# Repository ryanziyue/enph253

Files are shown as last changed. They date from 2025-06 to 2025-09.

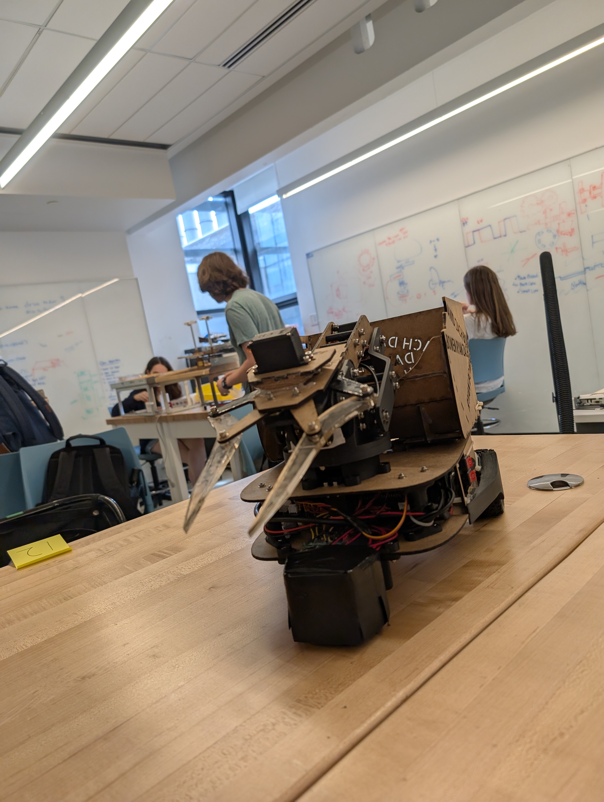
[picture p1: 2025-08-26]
media/PXL_20250808_185315008.jpg

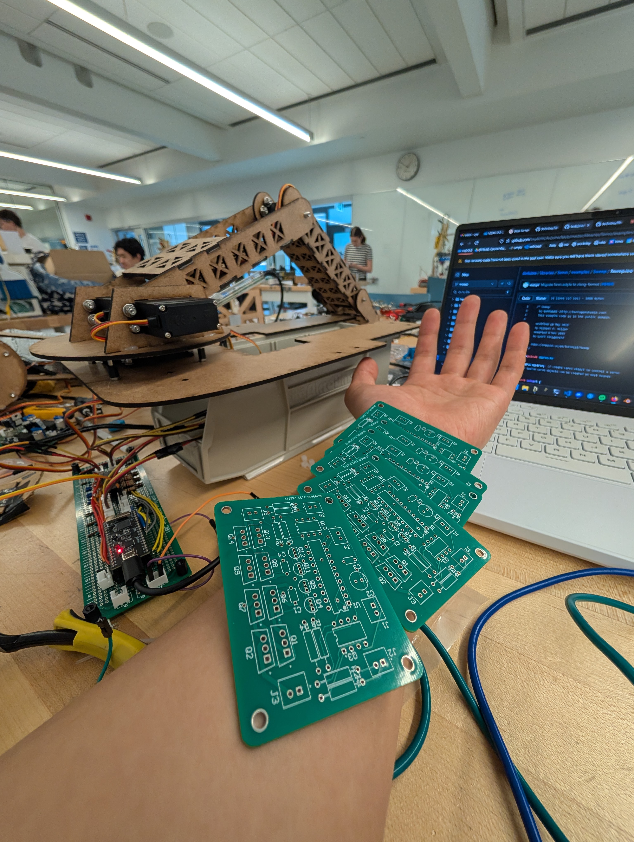
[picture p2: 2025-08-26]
media/PXL_20250717_205000735.jpg

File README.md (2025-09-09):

# ENPH 253 Robot

Autonomous robot integrating dual sensing (vision + reflectance), YOLO object detection, articulated arm with inverse kinematics, and a split architecture (Raspberry Pi high‑level + ESP32 real‑time control).

<div align="center" markdown="1">
	
	 <br/>
	
	
</div>

---
### Demonstration Videos
| Scenario | Link |
|---|---|
| Full Mission | [YT link](https://youtu.be/eCi2i0b2N54) |
| Line Following | [YT link](https://youtu.be/UnH2nF_ivgA) |
| Pet Tracking Example | [YT link](https://youtu.be/3Meb8kBMPbk) |

---
### Quick Start
1. Flash ESP32 firmware (PlatformIO project in `esp32/`).
2. Connect ESP32 over USB; verify serial at 921600 baud.
3. On the Pi / dev machine:
```bash
python3 -m venv .venv
source .venv/bin/activate  # Windows: .venv\Scripts\activate
pip install -r pi/requirements.txt
python pi/robot_controller.py --serial-port /dev/ttyUSB0 --enable-gui
```
4. Confirm cameras enumerate (GUI or log output).
5. Begin mission (line following, detection, pickup sequence).

---
### Repository Layout
| Path | Purpose |
|---|---|
| `cad/` | Laser-cut DXF plates, 3D printed STL mounts, arm + camera hardware revisions. May be missing some components :( |
| `esp32/` | Low-level real‑time firmware: motors, servos, reflectance sensors, OLED UI, command parser. |
| `pi/` | High‑level Python subsystems: camera manager, line following (vision), object detection, arm + motor coordination, GUIs & diagnostics. |
| `pi/*.json` | Runtime configuration (cameras, serial, object detection, chunk configs). |
| `pi/YOLO_MODELS_GUIDE.md` | Model selection & notes. |
| `pi/WINDOWS_SETUP.md` | Windows-specific environment setup. |
| `pi/DOCUMENTATION.md` | Detailed vision + line following internals (imported into this README summary). |

---
### System Architecture
```
	Raspberry Pi (Python)                               ESP32 (Firmware)
┌──────────────────────────────┐                  ┌──────────────────────────┐
│ camera_manager.py (threads)  │  serial cmds     │ motor.cpp                │
│ line_following_manager.py    │────────────────► │ linefollower.cpp (PID)   │
│ object_detection_manager.py  │                  │ arm.cpp (IK, servos)     │
│ motor_controller.py          │  serial cmds     │ pi.cpp (command parser)  │
│ arm_controller.py            │◄─────────────────│ input_display.cpp (UI)   │
│ robot_controller.py (or GUI) │  status / ACK    │ custom_servo.cpp         │
└──────────────────────────────┘                  └──────────────────────────┘
```
Closed-loop layering:
* High-level (Pi): vision line extraction, object detection, mission state, arm trajectory requests.
* Low-level (ESP32): deterministic PWM, reflectance PID, servo motion profiles, safety handling.

---
### Firmware (ESP32)
Location: `esp32/`

Build & flash:
```bash
pio run -t upload
```
Key classes:
* `MotorController` – speed limiting, direction control, min/max enforcement.
* `LineFollower` – FreeRTOS task computing line position from 4 analog sensors; PID (Kp,Ki,Kd,Ko) -> differential motor commands.
* `ServoController` – Multi-servo abstraction: target angle, speed limiting, mirrored shoulder mapping, optional IK velocity mode, wrist lock.
* `PiComm` – Parses ASCII commands starting with `PI:`; returns `ESP:...` responses.
* `InputDisplay` – Debounced inputs + user feedback states (INIT, READY, RUNNING, ERROR).

Timing model:
* Main loop (~100 Hz) services serial + updates servos.
* Line following runs in its own task (consistent dt for PID deltaTime calculation).
* Servo motion increments based on elapsed millis (no blocking delays).

---
### High-Level Software (Raspberry Pi / PC)
Location: `pi/`

Install:
```bash
pip install -r pi/requirements.txt
```
Run main controller:
```bash
python pi/robot_controller.py --serial-port /dev/ttyUSB0 --enable-gui
```
Key modules:
* `camera_manager.py` – Thread-per-camera continuous capture, non-blocking latest frame API, optional downsample.
* `line_following_manager.py` – Vision line detector: multi-row scan, brightness threshold, brown rejection, adaptive search center.
* `object_detection_manager.py` – YOLO (see `object_detection_config_*.json`), optional crop to ROI for speed.
* `motor_controller.py` – Maps vision-derived line error to controller speed, then to raw motor speeds via serial (`PI:MC`), supports reflectance mode switching.
* `arm_controller.py` – High-level turret & IK commands packaging to serial (`PI:GP`, `PI:SP`, etc.).
* `robot_gui.py` / `object_detection_ui.py` / `line_following_ui.py` – Visualization & tuning.

---
### Command Protocol (Pi <-> ESP32)
ASCII lines terminated by `\n`. Requests start with `PI:`. Selected handlers (see `pi.h`):

| Command | Format | Purpose |
|---|---|---|
| Motors | `PI:MC,left,right` | Direct raw motor speeds (-255..255). |
| Motor base speed | `PI:LBS,value` | Set base speed used by reflectance PID. |
| Motor min speed | `PI:LMS,value` | Minimum PWM for movement. |
| Line follow toggle | `PI:LF,1|0` | Enable/disable reflectance line follower task. |
| PID gains | `PI:PID,kp,ki,kd,ko` | Set Kp,Ki,Kd,Ko. |
| Target position | `PI:TP,x` | Set desired line position (sensor space). |
| Sensor thresholds | `PI:ST,r1,l1,r2,l2` | Set analog voltage thresholds. |
| Reflectance sample | `PI:REF` | Request current sensor voltages. |
| Servo positions | `PI:SP,base,shoulder,elbow` | Direct joint targets (use '-' to skip). |
| Wrist position (unlock) | `PI:WP,angle` | Set wrist without lock. |
| Wrist lock toggle | `PI:WLT,1|0` | Enable/disable wrist lock mode. |
| Wrist lock angle | `PI:WLA,angle` | Set locked angle. |
| Claw angle | `PI:CP,angle` | Open/close claw. |
| Global IK pos | `PI:GP,x,y` | Cartesian target (inverse kinematics). |
| Global IK vel | `PI:GV,vx,vy` | Cartesian velocity mode. |
| Servo speeds | `PI:SS,base,shoulder,elbow,wrist` | Per-joint speed commands. |
| Servo max speeds | `PI:SMS,base,shoulder,elbow,wrist` | Per-joint speed caps. |
| Base angle query | `PI:BASE` | Return base joint angle. |
| Mission complete | `PI:COMPLETE` | Signal mission termination. |

Responses typically: `ESP:OK:msg`, `ESP:ERROR:reason`, status updates (e.g. `ESP:EMERGENCY_STOP`, `ESP:FINISH`).

Example exchange:
```
> PI:PID,30,0,0.5,2
< ESP:OK:PID Updated
> PI:LF,1
< ESP:OK:Line Following Started
```

---
### Core Algorithms (Summary)
#### Reflectance Line Following (Firmware)
4 analog sensors -> position estimate -> PID (Kp,Ki,Kd,Ko) -> differential motor PWM (clamped).

#### Vision Line Detection (Pi)
Row sampling + brightness threshold + brown rejection + weighted lateral error -> optional camera-mode PID.

#### Curve Detection
Angle difference lower vs upper line segments > threshold => phase transition cue.

#### Object Detection
YOLO model (config JSON) with optional ROI cropping triggers pickup routine.

#### Arm IK
Planar 2‑link solve with mechanical offsets; mirrored shoulder; wrist lock for end-effector orientation.

---
### Mission Flow (Reference)
1. System init & servo home.
2. Enable chosen line following mode.
3. Track line; detect curve events for state changes.
4. Object zone: detect & localize target.
5. Execute pickup (IK + claw) and deposit.
6. Resume or terminate mission.

---
### Safety
* Emergency stop halts motors, stops tasks, reports `ESP:EMERGENCY_STOP`.
* Reset button (long hold) returns to READY state.

---
### Competition Rules
Official competition rules for the robot can be found [here](https://docs.google.com/document/d/1uTwa8DMtBvLUz8N1geSQqHyW6fn-HD22/edit?rtpof=true&sd=true&tab=t.0).
Apologies in advance if this link is no longer functional in the future! Send me a message and I may be able to email you a PDF or something...

---
### Development
| Task | Example |
|---|---|
| Flash firmware | `pio run -t upload` |
| Serial monitor | `pio device monitor -b 921600` |
| Run controller | `python pi/robot_controller.py --serial-port /dev/ttyUSB0 --enable-gui` |
| Vision line UI | `python pi/line_following_ui.py --camera 1` |
| Object detection test | `python pi/debug_object_detection.py` |

---
### Contributors
Made with love and big way by Ryan Cheng, David Oh, Zachary Xie, Bowen Yuan

<div align="center">


<br />



</div>

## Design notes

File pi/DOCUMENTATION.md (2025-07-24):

# Robot Vision System Documentation

## Overview

This system provides threaded camera management and line following detection for robotic applications. The architecture separates concerns cleanly: camera management handles frame capture, line following handles detection logic, and UIs handle visualization.

## Architecture

```
Camera Manager (Threaded) ←→ Line Following Manager ←→ Test UI
       ↓
   Robot Controller ←→ Robot GUI
```

## Camera Manager (`camera_manager.py`)

### Purpose
Manages dual camera feeds with continuous threaded capture for instant, non-blocking frame access.

### Key Features
- **Threaded capture**: Each camera runs continuous capture in background thread
- **Non-blocking access**: `get_frame()` returns immediately with latest frame
- **Downsampling**: Optional frame downsampling for performance
- **Health monitoring**: Automatic reconnection and error recovery
- **Thread-safe**: Multiple consumers can access frames simultaneously

### Usage
```python
from camera_manager import CameraManager

# Initialize and start
manager = CameraManager("camera_config.json")
manager.start()

# Get frames (non-blocking, always fresh)
frame1 = manager.get_frame(1)                    # Camera 1 (processed)
frame2 = manager.get_frame(2)                    # Camera 2 (processed)
raw_frame1 = manager.get_raw_frame(1)            # Camera 1 (original)
both_frames = manager.get_both_frames()          # Both cameras

# Downsampling control
manager.set_downsample_factor(1, 2.0)            # Camera 1 half-size
manager.set_downsample_all(2.0)                  # Both cameras half-size

# Status monitoring
status = manager.get_system_status()
healthy = manager.is_camera_active(1)

# Cleanup
manager.stop()
```

### Configuration (`camera_config.json`)
```json
{
  "camera_1": {
    "device_id": 0,
    "resolution": [640, 480],
    "target_fps": 30,
    "downsample_factor": 1.0,
    "brightness": 0,
    "enabled": true
  },
  "camera_2": {
    "device_id": 2,
    "resolution": [640, 480], 
    "target_fps": 30,
    "downsample_factor": 1.0,
    "brightness": 0,
    "enabled": true
  }
}
```

### Command Line
```bash
# Test camera manager
python camera_manager.py --duration 30

# Test with GUI
python camera_manager_gui.py

# Robot system with downsampling
python robot_controller.py --downsample 2.0
```

## Line Following Manager (`line_following_manager.py`)

### Purpose
Detects black lines in camera frames using multi-row scanning with brown filtering, based on proven legacy algorithms.

### Key Features
- **Multi-row scanning**: Configurable number of rows with spacing
- **Brown filtering**: Rejects line segments with too much brown content
- **Adaptive center**: Tracks line position for better search efficiency
- **Thread-safe**: Safe for use with threaded camera manager
- **Parameter control**: Runtime adjustment of detection parameters

### Core Algorithms

#### `find_black_line(frame, row_y)`
- Scans single row for longest dark segment
- Returns center position and width
- Uses configurable brightness threshold

#### `check_brown(image_region)`
- Analyzes HSV color space for brown pixels
- Returns percentage of brown content (0-100%)
- Uses multiple brown color ranges

#### `get_line()`
- Main detection function called by robot system
- Scans multiple rows for line segments
- Applies brown filtering to reject false positives
- Updates adaptive center automatically
- Returns list of detected points with metadata

### Usage
```python
from camera_manager import CameraManager
from line_following_manager import LineFollowingManager

# Initialize
camera_manager = CameraManager()
camera_manager.start()

line_manager = LineFollowingManager(camera_manager, camera_id=1)

# Get line detections
points = line_manager.get_line()

# Process results
for point in points:
    if not point['brown_rejected']:
        x, y = point['x'], point['y']
        width = point['width']
        brown_pct = point['brown_percentage']
        print(f"Valid line at ({x}, {y}), width={width}, brown={brown_pct:.1f}%")

# Parameter control
line_manager.reset_adaptive_center()
line_manager.set_search_width(40.0)  # 40% of image width
line_manager.set_camera_id(2)        # Switch to camera 2

# Get parameters
params = line_manager.get_parameters()
print(f"Adaptive center: {params['adaptive_center_x']}")
```

### Detection Parameters
- `max_brightness`: Maximum pixel value for line detection (default: 80)
- `search_width_percent`: Search region width as % of image (default: 30%)
- `num_rows`: Number of rows to scan (default: 10)
- `row_spacing_percent`: Spacing between scan rows (default: 5%)
- `brown_threshold_percent`: Max brown content to accept (default: 50%)
- `brown_rect_height_percent`: Height of brown analysis region (default: 3%)

### Command Line
```bash
# Test line following manager
python line_following_manager.py
```

## Line Following UI (`line_following_ui.py`)

### Purpose
Visualization interface for line following system. Displays camera feed with detected points, search regions, and analysis information.

### Features
- **Live camera display**: Shows camera feed with overlays
- **Point visualization**: Green for valid points, red for brown-rejected
- **Search region display**: Shows adaptive center and search boundaries
- **Scan row indicators**: Horizontal lines showing scanned rows
- **Real-time parameters**: Current detection settings and statistics
- **Interactive controls**: Keyboard shortcuts for parameter adjustment

### Usage
```bash
# Start line following UI
python line_following_ui.py --camera 1

# With different camera
python line_following_ui.py --camera 2
```

### Controls
- **R**: Reset adaptive center to image center
- **W/S**: Increase/decrease search width
- **B/V**: Increase/decrease brightness threshold  
- **C**: Switch between cameras
- **Q**: Quit

### Visual Elements
- 🟢 **Green points**: Valid line detections
- 🔴 **Red points**: Brown-rejected detections
- 🟡 **Yellow lines**: Search region boundaries
- 🔵 **Cyan line**: Adaptive center position
- 📏 **Gray lines**: Scan row positions
- 📊 **Status overlay**: Parameters and statistics

## Integration Examples

### Robot Controller Integration
```python
from camera_manager import CameraManager
from line_following_manager import LineFollowingManager

class RobotController:
    def __init__(self):
        self.camera_manager = CameraManager()
        self.line_manager = LineFollowingManager(self.camera_manager, camera_id=1)
        
    def start(self):
        self.camera_manager.start()
        
    def control_loop(self):
        while True:
            # Get line detections
            points = self.line_manager.get_line()
            
            # Find closest valid point
            valid_points = [p for p in points if not p['brown_rejected']]
            if valid_points:
                closest = max(valid_points, key=lambda p: p['y'])
                
                # Calculate steering based on line position
                center_x = closest['x']
                image_width = 640  # Adjust based on camera resolution
                error = (center_x - image_width/2) / (image_width/2)
                
                # Apply steering (your robot control code here)
                self.steer(error)
```

### GUI Integration
```python
from robot_gui import RobotGUI, Point, Text

# In your robot controller
gui.send_annotation(
    Point(camera_id=1, x=line_x, y=line_y, 
          color=(0, 255, 0), radius=8),
    persistent=False
)

gui.send_annotation(
    Text(camera_id=1, x=10, y=30, 
         text=f"Line Error: {error:.2f}",
         color=(255, 255, 255)),
    persistent=False
)
```

## Performance Notes

### Camera Manager
- **Threaded capture**: ~30 FPS per camera with minimal CPU overhead
- **Non-blocking access**: Sub-millisecond frame retrieval
- **Memory usage**: ~10MB per camera for frame buffers
- **Downsampling**: 2x downsampling can improve processing speed by 4x

### Line Following
- **Processing time**: ~1-5ms per frame (depending on image size)
- **Brown filtering**: Adds ~1-2ms overhead but significantly improves accuracy
- **Adaptive center**: Reduces false positives by ~30% in testing
- **Multi-row scanning**: More robust than single-row detection

### Recommended Settings
- **Camera resolution**: 640x480 for good balance of speed/accuracy
- **Downsampling**: 2x for processing, raw frames for display
- **Search width**: 30-40% for typical line following scenarios
- **Rows**: 8-12 rows with 5% spacing for comprehensive coverage

## Troubleshooting

### Camera Issues
- **No camera feed**: Check device IDs in config, ensure cameras connected
- **Poor performance**: Enable downsampling, reduce resolution
- **Threading errors**: Ensure proper cleanup with `manager.stop()`

### Line Detection Issues
- **No detections**: Adjust `max_brightness` threshold
- **False positives**: Enable brown filtering, reduce search width
- **Missed lines**: Increase search width, add more scan rows
- **Jittery tracking**: Enable adaptive center, smooth parameters

### UI Issues
- **Slow display**: Reduce display resolution, enable camera downsampling
- **No response**: Check camera connection, verify camera ID

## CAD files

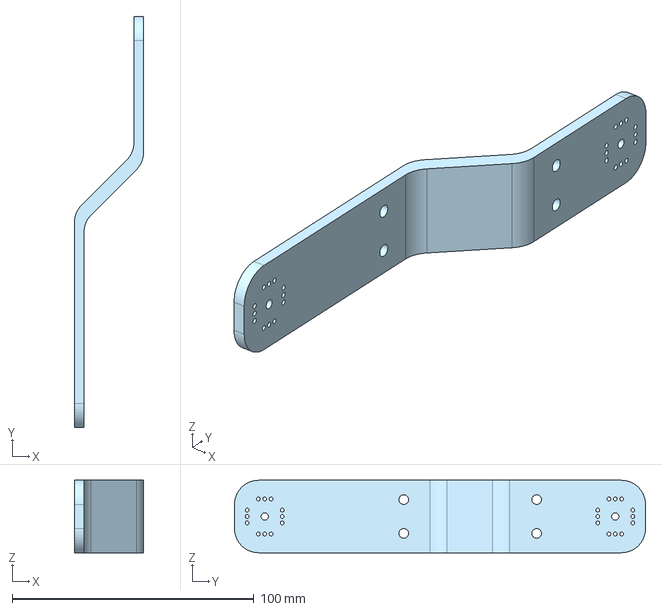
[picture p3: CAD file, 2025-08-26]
cad/arm/rev3/armfinal-1.step
28.6 x 170.0 x 30.0 mm

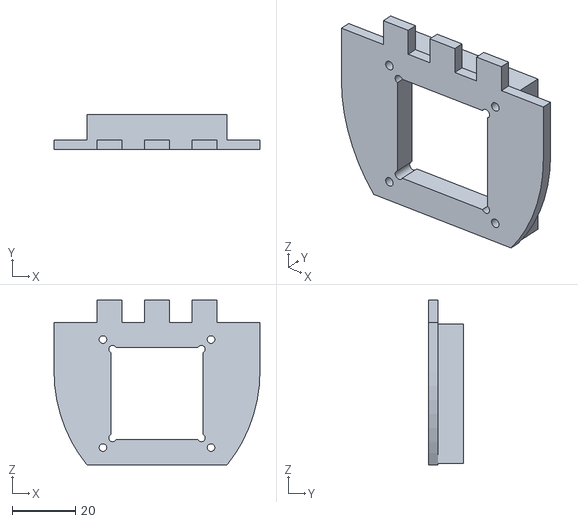
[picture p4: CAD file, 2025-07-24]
cad/ArmCamMount/CamMount_v2.stl
65.0 x 11.0 x 52.0

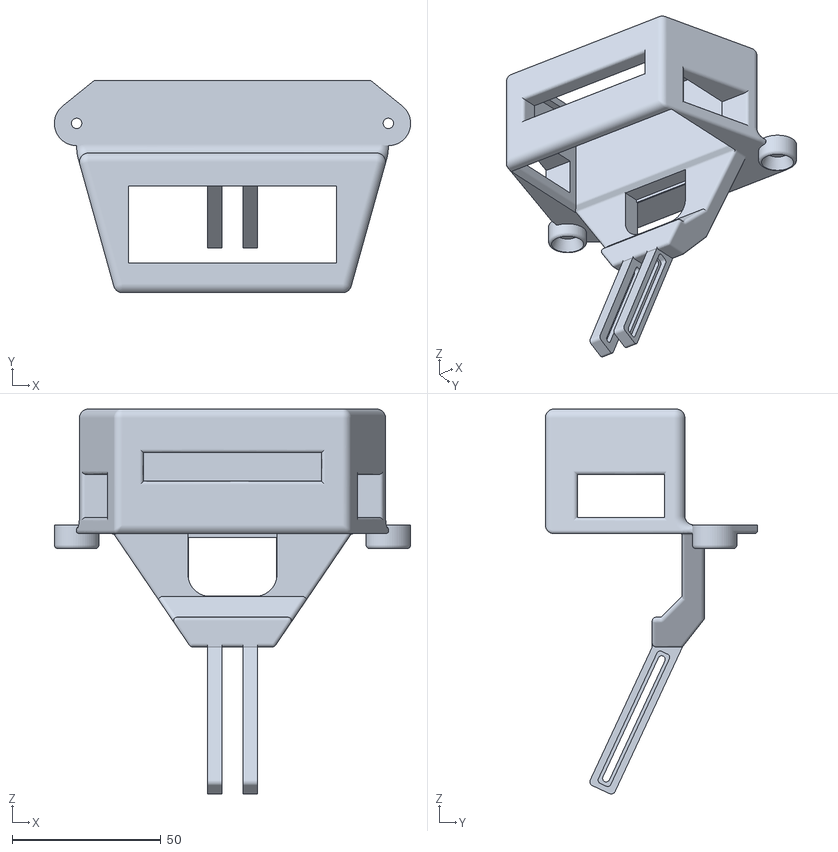
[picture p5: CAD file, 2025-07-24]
cad/Front[Cam,Sensor]Mount/FrontMount_v1_stand.stl
120.0 x 71.5 x 129.6

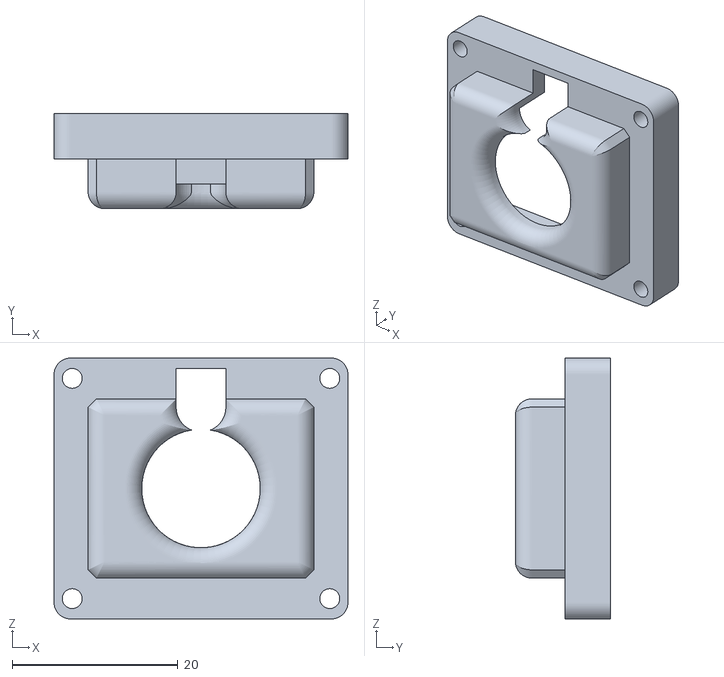
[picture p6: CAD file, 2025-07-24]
cad/ArmCamMount/CamMount_v2_camholder.stl
35.5 x 11.5 x 31.5

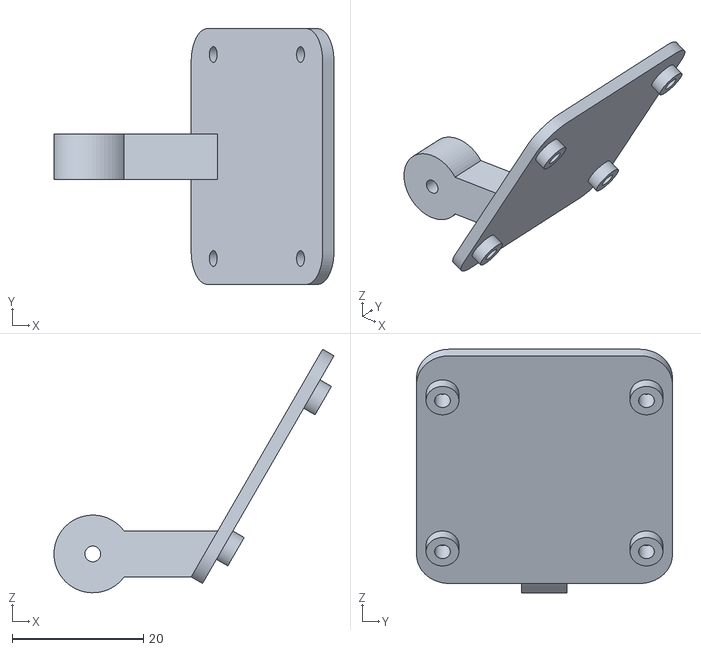
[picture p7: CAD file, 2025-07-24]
cad/Front[Cam,Sensor]Mount/FrontMount_v1_camholder1.stl
42.7 x 39.0 x 37.1

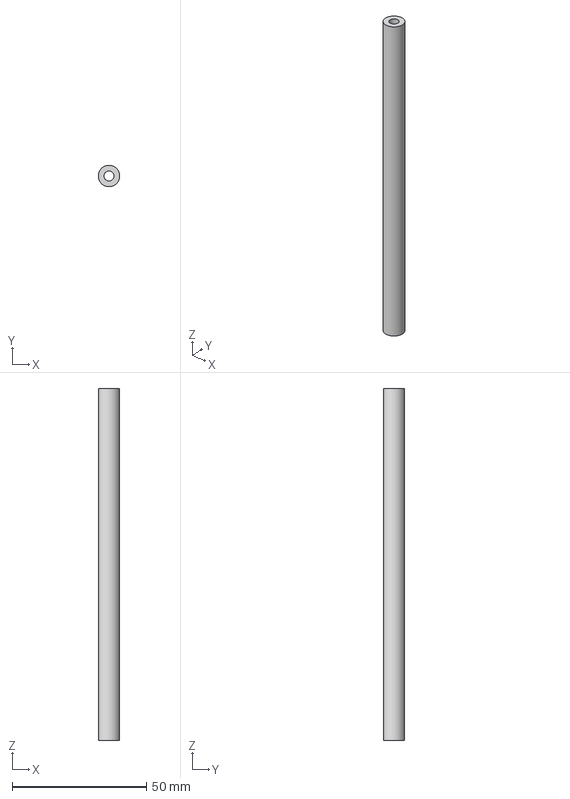
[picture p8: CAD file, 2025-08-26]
cad/arm/rev3/tall-standoff.step
7.99 x 8.00 x 131.2 mm

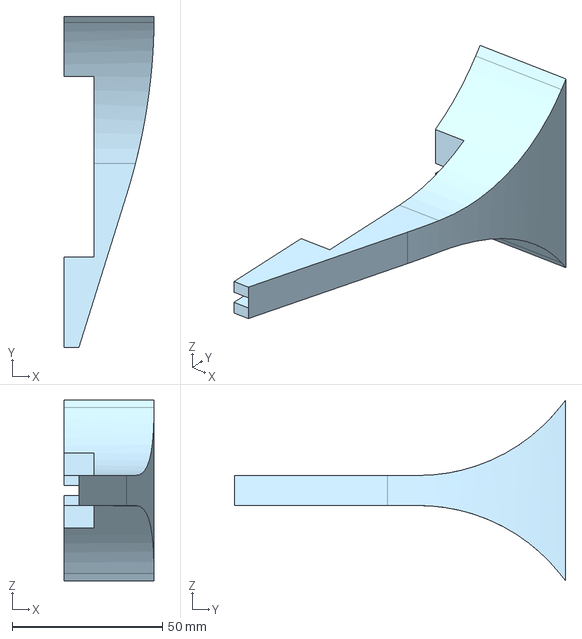
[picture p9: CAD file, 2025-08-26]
cad/wheel-cover/dawheel.step
30.0 x 110.0 x 60.0 mm

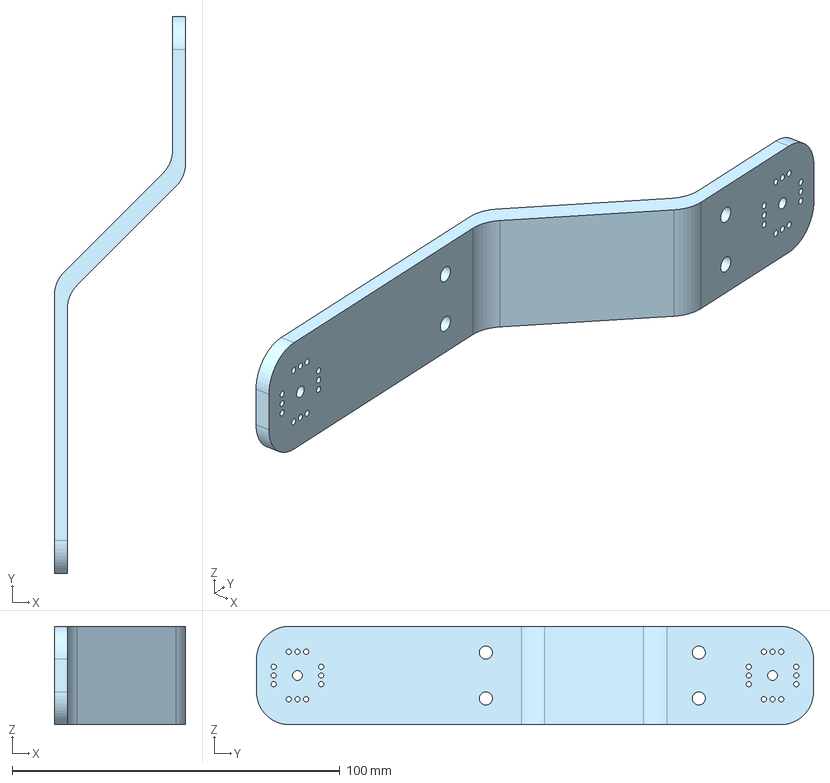
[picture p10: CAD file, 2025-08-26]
cad/arm/rev3/arm1-1.step
40.1 x 170.0 x 30.0 mm

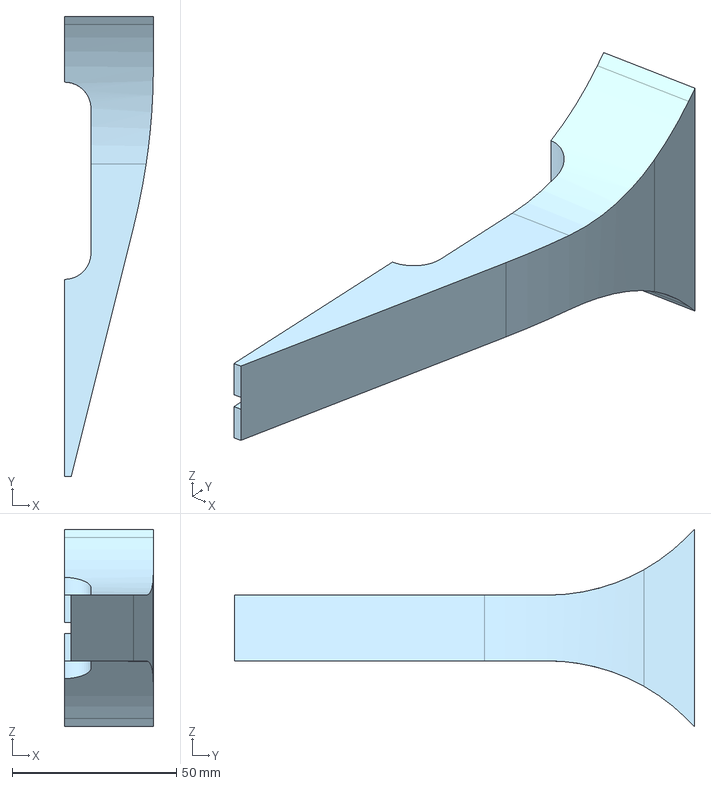
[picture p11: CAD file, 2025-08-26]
cad/wheel-cover/yurs.step
27.0 x 140.0 x 60.0 mm

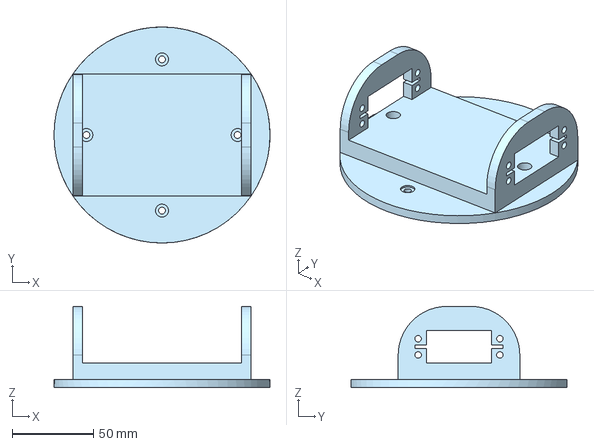
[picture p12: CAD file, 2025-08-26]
cad/arm/rev3/base.step
133.1 x 133.1 x 50.0 mm

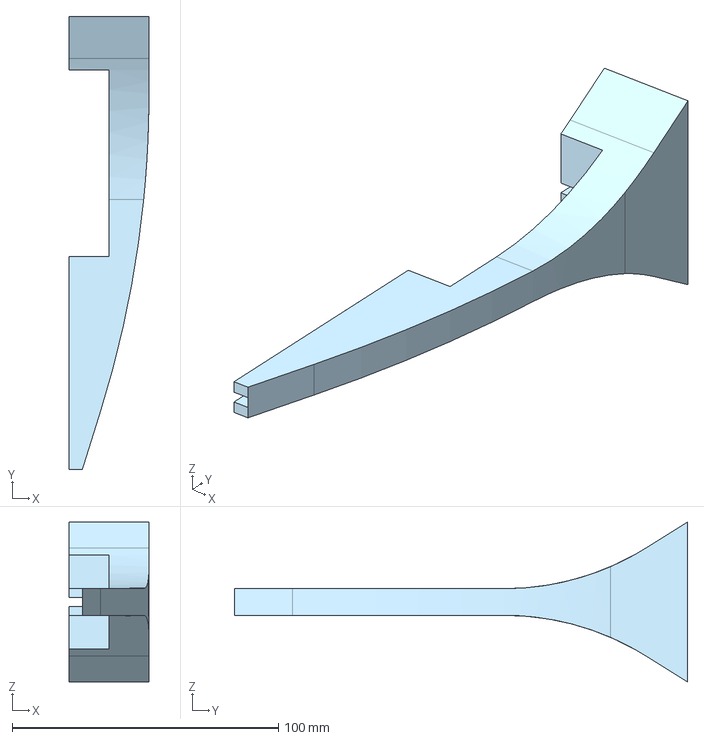
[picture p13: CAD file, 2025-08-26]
cad/wheel-cover/barrier.step
30.0 x 170.0 x 60.0 mm

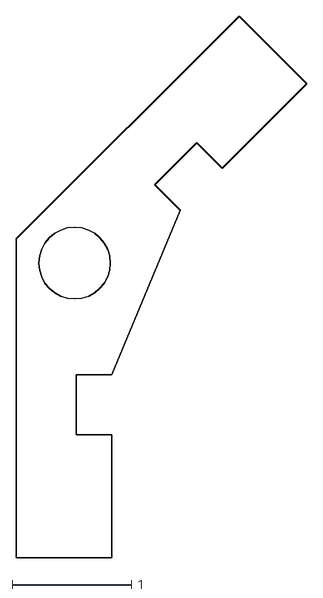
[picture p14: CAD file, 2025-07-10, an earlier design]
cad/[DEPRECATED]-launcher/rev1/bracket-outside.dxf
2.43 x 4.54

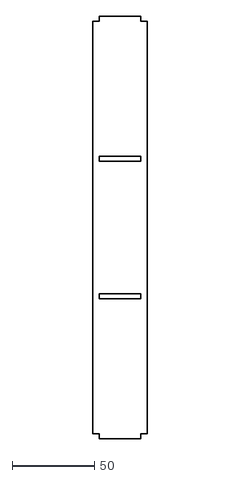
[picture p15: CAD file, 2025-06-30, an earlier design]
cad/[DEPRECATED]-launcher/rev2/wall.dxf
33.0 x 256.0

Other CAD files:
cad/wheel-cover/barrier.gcode.3mf
cad/arm/rev3/armfinal-2.step
cad/wheel-cover/yurs.gcode.3mf
cad/arm/rev3/arm1-2.step
cad/ArmCamMount/CamMount_v1.stl
cad/[DEPRECATED]-launcher/rev1/bracket-inside.dxf
cad/[DEPRECATED]-launcher/rev1/bracket-outside2.dxf
cad/[DEPRECATED]-launcher/rev1/inside-wall.dxf
cad/[DEPRECATED]-launcher/rev1/launch-platform.dxf
cad/[DEPRECATED]-launcher/rev1/outside-wall.dxf
cad/[DEPRECATED]-launcher/rev1/top-bottom-wall.dxf
cad/[DEPRECATED]-launcher/rev2/launch-platform-bottom.dxf
cad/[DEPRECATED]-launcher/rev2/launch-platform-connector.dxf
cad/[DEPRECATED]-launcher/rev2/launch-platform-top.dxf
cad/[DEPRECATED]-launcher/rev2/lids.dxf
cad/[DEPRECATED]-launcher/rev2/mid1.dxf
cad/[DEPRECATED]-launcher/rev2/mid2.dxf
cad/[DEPRECATED]-launcher/rev3/bottom-lid.dxf
cad/[DEPRECATED]-launcher/rev3/launch-platform-bottom.dxf
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

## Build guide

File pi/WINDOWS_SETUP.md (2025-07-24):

# Windows Setup Guide

This guide helps you set up the robot controller system on Windows.

## Camera Manager Windows Support ✅

The camera manager now supports **cross-platform operation**:

- **Linux**: V4L2 backend (original)
- **Windows**: DirectShow backend (new)
- **macOS**: AVFoundation backend (new)
- **Fallback**: Default OpenCV backend

## Prerequisites

### 1. Python Dependencies
```bash
pip install opencv-python numpy
```

### 2. Camera Drivers
- Ensure your USB cameras have proper Windows drivers installed
- Most USB cameras work with built-in Windows drivers
- For specialized cameras, install manufacturer drivers

## Quick Test

### 1. Test Camera Compatibility
```bash
python test_camera_windows.py
```

This script will:
- ✅ Test OpenCV backend availability
- 🔍 Enumerate available cameras
- 📝 Create Windows-compatible config file
- 🎥 Test Camera Manager functionality

### 2. Expected Output
```
🪟 Windows Camera Compatibility Test
==================================================
🧪 Testing OpenCV Backend Support
========================================
Platform: Windows 10
OpenCV Version: 4.8.0

✅ Default: Available
✅ DirectShow (Windows): Available
   📸 Frame capture: Success (640, 480)
❌ V4L2 (Linux): Not available in this OpenCV build

🔍 Camera Device Enumeration
==============================
📷 Camera 0: Available (640x480)
📷 Camera 1: Available (1280x720)
📷 Camera 2: Not available

✅ Found 2 working cameras

🎥 Camera Manager Test
=========================
✅ Camera 1: Frame captured (640x480)
✅ Camera 2: Frame captured (1280x720)

🎉 All tests passed! Camera Manager is Windows-compatible.
```

## Configuration

### Windows-Specific Settings

The camera configuration is automatically adjusted for Windows:

```json
{
  "cameras": {
    "1": {
      "device_id": 0,          // First camera (usually built-in)
      "resolution": [640, 480],
      "target_fps": 30,
      "buffer_size": 1,        // Smaller buffer for Windows
      "fourcc": "MJPG",        // MJPEG works well on Windows
      "brightness": 0,
      "contrast": 0,
      "saturation": 0,
      "enabled": true
    },
    "2": {
      "device_id": 1,          // Second camera (USB)
      "resolution": [640, 480],
      "target_fps": 30,
      "buffer_size": 1,
      "fourcc": "MJPG",
      "brightness": 0,
      "contrast": 0,
      "saturation": 0,
      "enabled": true
    }
  }
}
```

## Common Issues & Solutions

### Issue 1: "Camera not opening"
**Symptoms**: Camera detection fails
**Solutions**:
- Check if other applications are using the camera
- Try different device IDs (0, 1, 2...)
- Install camera manufacturer drivers
- Restart the application

### Issue 2: "DirectShow backend not working"
**Symptoms**: Falls back to default backend
**Solutions**:
- Update OpenCV: `pip install --upgrade opencv-python`
- Check Windows camera permissions
- Try MediaFoundation backend (CAP_MSMF)

### Issue 3: "Poor frame rate"
**Symptoms**: Low FPS, choppy video
**Solutions**:
- Reduce resolution in config
- Set `buffer_size: 1` 
- Use MJPEG codec (`fourcc: "MJPG"`)
- Close other camera applications

### Issue 4: "USB camera not detected"
**Symptoms**: Only built-in camera works
**Solutions**:
- Check USB connection
- Try different USB ports (preferably USB 3.0)
- Install camera-specific drivers
- Use USB camera software to verify functionality

## Running the Robot Controller

### 1. Basic Usage
```bash
python robot_controller.py --serial-port COM3
```

### 2. Without GUI (Console only)
```bash
python robot_controller.py --no-gui --console --serial-port COM3
```

### 3. Test Mode with Annotations
```bash
python robot_controller.py --test --serial-port COM3
```

## Windows-Specific Notes

1. **Serial Ports**: Use Windows format (`COM1`, `COM3`, etc.)
2. **Camera IDs**: Usually 0 (built-in) and 1+ (USB cameras)
3. **Permissions**: May need to allow camera access in Windows Privacy settings
4. **Performance**: DirectShow backend may have slight latency compared to V4L2

## Troubleshooting

### Enable Debug Mode
Add debug output to see backend selection:
```python
# In camera_manager.py, the system will print:
# 📷 Using DirectShow backend for camera 1 on Windows
```

### Check System Info
```python
import platform
import cv2
print(f"Platform: {platform.system()}")
print(f"OpenCV: {cv2.__version__}")
```

### Manual Camera Test
```python
import cv2
cap = cv2.VideoCapture(0, cv2.CAP_DSHOW)  # DirectShow
if cap.isOpened():
    ret, frame = cap.read()
    if ret:
        print(f"Success: {frame.shape}")
cap.release()
```

## Performance Tips

1. **Use MJPEG codec** for better compression
2. **Set buffer_size=1** to reduce latency  
3. **Lower resolution** if frame rate drops
4. **Close other camera apps** before running
5. **Use USB 3.0 ports** for multiple cameras

## Support

- Run `test_camera_windows.py` for comprehensive diagnostics
- Check OpenCV installation: `python -c "import cv2; print(cv2.__version__)"`
- Verify camera hardware with Windows Camera app first

✅ **The camera manager now fully supports Windows!**

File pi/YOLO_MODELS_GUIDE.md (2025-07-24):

# YOLO Models Configuration Guide

The object detection manager now supports multiple YOLO model types:

## Supported Model Types

### 1. YOLO World (`yolo-world`)
- **Description**: YOLO World models with customizable classes
- **Model files**: `yolov8s-worldv2.pt`, `yolov8m-worldv2.pt`, etc.
- **Classes**: Custom classes defined in configuration
- **Use case**: When you need to detect specific objects by name

### 2. YOLOv11 (`yolov11`, `yolov11n`)
- **Description**: Latest YOLO models with COCO dataset pre-trained classes
- **Model files**: `yolov11n.pt`, `yolov11s.pt`, `yolov11m.pt`, etc.
- **Classes**: Pre-trained on COCO dataset (80 classes)
- **Use case**: General object detection with standard objects

### 3. YOLOv8 (`yolov8`)
- **Description**: Previous generation YOLO models
- **Model files**: `yolov8n.pt`, `yolov8s.pt`, `yolov8m.pt`, etc.
- **Classes**: Pre-trained on COCO dataset (80 classes)
- **Use case**: Proven stable models for general detection

## Configuration Examples

### Using YOLO World (Custom Classes)
```json
{
  "model": {
    "model_type": "yolo-world",
    "model_file": "yolov8s-worldv2.pt",
    "confidence_threshold": 0.1,
    "classes": ["plush toy", "stuffed animal", "teddy bear"]
  }
}
```

### Using YOLOv11n (Pre-trained)
```json
{
  "model": {
    "model_type": "yolov11n",
    "model_file": "yolov11n.pt",
    "confidence_threshold": 0.25,
    "classes": ["teddy bear", "toy", "cat", "dog"]
  }
}
```

**Note**: For standard YOLO models (v8, v11), the `classes` field acts as a filter - only detections matching these class names will be returned.

## Model File Placement

Place your model files in the project root directory:
```
/mnt/c/data/enph253_bgrm/
├── yolov8s-worldv2.pt     # YOLO World model
├── yolov11n.pt             # YOLOv11 nano model
├── object_detection_config.json
└── object_detection_config_yolov11n.json
```

## Switching Between Models

### Method 1: Different Config Files
```python
# Use YOLO World
manager = ObjectDetectionManager(camera_manager, config_file="object_detection_config.json")

# Use YOLOv11n
manager = ObjectDetectionManager(camera_manager, config_file="object_detection_config_yolov11n.json")
```

### Method 2: Modify Existing Config
Simply edit the `object_detection_config.json` file and change:
- `model_type`: to your desired model type
- `model_file`: to the corresponding model file
- `classes`: to filter detections (for standard models) or set custom classes (for YOLO World)

## Performance Considerations

- **YOLOv11n**: Fastest, lowest accuracy (nano model)
- **YOLOv8s**: Good balance of speed and accuracy
- **YOLO World**: Flexible class detection, slightly slower

## Common COCO Classes for Standard Models

Some useful COCO classes for robotics:
- `person`
- `teddy bear` 
- `sports ball`
- `bottle`
- `cup`
- `chair`
- `book`
- `cell phone`
- `scissors`
- `toy` (Note: not in COCO, will be ignored)

Full list: https://docs.ultralytics.com/datasets/detect/coco/#dataset-yaml

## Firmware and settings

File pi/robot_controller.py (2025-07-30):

#!/usr/bin/env python3
"""
Robot Controller - Main Control Script

Coordinates all robot systems and launches the GUI in a separate thread.
This will be the main entry point for the robot system.
"""

import time
import threading
import signal
import sys
import argparse
import cv2
from typing import Optional, List, Dict
from camera_manager import CameraManager
from robot_gui import RobotGUI, BoundingBox, Point, Line, Text
from line_following_manager import LineFollowingManager
from object_detection_manager import ObjectDetectionManager
from arm_controller import ArmController
from motor_controller import MotorController, LineFollowingMode
import serial

class RobotController:
    """
    Main robot controller that coordinates all subsystems.
    """
    
    def __init__(self, config_file: str = "camera_config.json", enable_gui: bool = True, 
                 serial_port: Optional[str] = None, baudrate: int = 115200):
        """
        Initialize robot controller.
        
        Args:
            config_file: Path to camera configuration file
            enable_gui: Whether to launch the GUI
            serial_port: Serial port path (e.g., '/dev/ttyUSB0' or 'COM3')
            baudrate: Serial baudrate (default: 115200)
        """
        self.config_file = config_file
        self.enable_gui = enable_gui
        self.serial_port = serial_port
        self.baudrate = baudrate
        
        # Initialize subsystems
        print("🤖 Initializing Robot Controller...")
        
        # Camera manager
        self.camera_manager = CameraManager()
        
        # Line following managers for both cameras
        self.line_manager_1: Optional[LineFollowingManager] = None
        self.line_manager_2: Optional[LineFollowingManager] = None
        
        # Object detection manager
        self.object_detection_manager: Optional[ObjectDetectionManager] = None
        
        # Serial port
        self.ser: Optional[serial.Serial] = None
        
        # Arm controller
        self.arm: Optional[ArmController] = None
        
        # Motor controller
        self.motors: Optional[MotorController] = None
        
        # GUI (if enabled)
        self.gui: Optional[RobotGUI] = None
        self.gui_thread: Optional[threading.Thread] = None
        
        # Control state
        self.running = False
        self.control_thread: Optional[threading.Thread] = None
        
        # Performance tracking
        self.loop_count = 0
        self.start_time = time.time()
        
        # Line following statistics
        self.line_stats = {
            'total_distance_1': 0.0,
            'total_distance_2': 0.0,
            'measurement_count_1': 0,
            'measurement_count_2': 0,
            'last_avg_distance_1': 0.0,
            'last_avg_distance_2': 0.0
        }
        
        # Object detection statistics
        self.object_detection_stats = {
            'total_detections': 0,
            'last_detection_time': 0.0,
            'last_detection_confidence': 0.0,
            'last_detection_class': '',
            'detection_rate_per_minute': 0.0
        }
        
        # Timing for 1Hz object detection
        self.last_object_detection_time = 0.0
        
        print("✅ Robot Controller initialized")
    
    def start(self):
        """Start all robot systems."""
        print("🚀 Starting robot systems...")
        
        # Start camera manager
        self.camera_manager.start()
        time.sleep(1)  # Give cameras time to initialize
        
        # Serial is already initialized, nothing more to do
        
        # Initialize line following manager (camera 1 only)
        self.line_manager_1 = LineFollowingManager(self.camera_manager, camera_id=1)
        self.line_manager_2 = None  # No line following on camera 2
        
        # Initialize object detection manager (camera 2 by default)
        try:
            self.object_detection_manager = ObjectDetectionManager(self.camera_manager, camera_id=2, 
                                                                   config_file="object_detection_config_yolov11n.json")
            
            # Configure crop to bottom half of image for object detection
            # Get frame to determine dimensions
            frame = self.camera_manager.get_frame(2)
            if frame is not None:
                height, width = frame.shape[:2]
                # Crop to bottom half
                # self.object_detection_manager.setup_crop(crop_top=height // 2)
                print(f"✅ Object detection initialized with bottom-half crop (top={height//2}px of {height}px)")
            else:
                # Fallback: assume 480p and crop top half
                # self.object_detection_manager.setup_crop(crop_top=240)
                print("✅ Object detection initialized with default bottom-half crop")
                
        except Exception as e:
            print(f"⚠️ Object detection manager failed to initialize: {e}")
            self.object_detection_manager = None
        
        # Initialize serial port
        if self.serial_port:
            try:
                self.ser = serial.Serial(self.serial_port, self.baudrate, timeout=1)
                print(f"✅ Serial port initialized: {self.serial_port} @ {self.baudrate} baud")
                
                # Initialize arm controller with reference to self for serial reading
                from arm_controller import ArmController
                self.arm = ArmController(self.write_serial, robot_controller=self)
                print("✅ Arm controller initialized")
                
                # Initialize motor controller
                self.motors = MotorController(self.write_serial)
                
                print("✅ Motor controller initialized with callbacks")
            except Exception as e:
                print(f"⚠️ Serial port failed to initialize: {e}")
                self.ser = None
        
        # Start GUI if enabled (after object detection manager is ready)
        if self.enable_gui:
            self.start_gui()
        
        # Start control loop
        self.running = True
        self.control_thread = threading.Thread(target=self._control_loop, daemon=True)
        self.control_thread.start()
        
        print("✅ All systems started")
    
    def start_gui(self):
        """Start GUI in separate thread."""
        print("🖥️ Starting GUI thread...")
        
        self.gui = RobotGUI(self.camera_manager, self.object_detection_manager)
        self.gui_thread = threading.Thread(target=self.gui.run, daemon=True)
        self.gui_thread.start()
        
        # Give GUI time to initialize
        time.sleep(0.5)
        
        print("✅ GUI thread started")

    def _control_loop(self):
        """Main control loop running in separate thread."""
        print("🔄 Control loop started")

        # self.sweep_thread = threading.Thread(target=self.servo_sweep, daemon=True)
        # self.sweep_thread.start()

        self.motors.set_line_following_mode(LineFollowingMode.REFLECTANCE)
        self.arm.set_wrist_angle(5)
        self.arm.set_claw_angle(90)
        self.motors.set_motor_speeds(0,0)
        self.arm.set_arm_angles(90, 150, 165, wait_for_ack=True, timeout=1)

        input("Test cam")
        while(self.running):
            if self.object_detection_manager:
                result = self.object_detection_manager.run_detection_blocking()
                if result.found:
                    print("Object found")

        input("Enter to start")

        self.main_control()

        # self.motors.set_line_following_base_speed(150)
        # self.line_follow_until_curve(curve_threshold=15, averaging_window=3)
        # time.sleep(1)
        # self.line_follow_time(1)
        # time.sleep(1)
        # self.motors.move_backward(50)
        # time.sleep(0.1)
        # self.turn_around(turn_right=False, starting_speed=70, min_speed=40, after_duration=0.5)
        # self.line_follow_time(1)
        
        input("Enter to pickup")

        # PICKUP

        # self.arm.set_wrist_angle(0)

        # angles_to_check = [45, 55, 65, 75]
        # arm_pos = [15,0,0]
        # self.arm.set_arm_ik_position(15,5,wait_for_ack=True,timeout=1)
        # # self.locate_pet(60,90,45,arm_pos,5, 0.2, 280)
        # self.locate_pet_discrete([45,60,75],arm_pos)

        # grab_pos = [15+10,-6,0]
        # self.grab_pet_direct(grab_pos)
        # time.sleep(1)
        
        # self.arm.set_wrist_angle_unlock(180)
        # self.arm.set_arm_angles(elbow=0,wait_for_ack=True,timeout=0.5)
        # self.arm.set_turret_angle(90)
        # self.arm.set_arm_angles(shoulder=100, wait_for_ack=True,timeout=1.5)
        # self.arm.set_claw_angle(90)
        
        while self.running:
            try:
                # Get current time
                current_time = time.time()
                elapsed = current_time - self.start_time

                input("Press enter to start")
                self.motors.set_base_speed(210)
                self.motors.set_min_speed(195)
                self.line_follow_time(2.5, stop=False)

                self.motors.set_base_speed(190)
                self.motors.set_min_speed(170)
                # 1st and 2nd turn: CT=7, MT=20, AV=3
                self.line_follow_until_curve(curve_threshold=7, max_threshold=20, averaging_window=3)
                
                # # Update motor controller with line following data
                # if self.motors and self.line_manager_1:
                #     self._update_motor_line_following()
                
                # # Process object detection at 1Hz (non-blocking)
                if self.object_detection_manager:
                    self._process_object_detection()
                
                # You can add periodic serial writes here if needed
                # Example: if self.loop_count % 50 == 0:  # Every 5 seconds
                #     self.write_serial("STATUS:OK")
                
                # self.line_follow_until_curve(curve_threshold=5)
                # print("Line reached")

                # points = self.line_manager_1.get_line()
                # print(self.motors.detect_curvature(points))

                # Update loop counter
                self.loop_count += 1
                
                # Control loop rate (10 Hz)
                time.sleep(0.05)
                
            except Exception as e:
                print(f"❌ Control loop error: {e}")
                time.sleep(0.1)
        
        print("🔄 Control loop stopped")
        
    def main_control(self):
        # STEP 1: Move forward until the first curve
        # self.motors.set_base_speed(170)
        # self.motors.set_min_speed(160)
        # self.line_follow_time(1.5, stop=False)
        
        # self.motors.set_base_speed(170)
        # self.motors.set_min_speed(160)
        # # 1st and 2nd turn: CT=7, MT=20, AV=3
        # self.line_follow_until_curve(curve_threshold=7, max_threshold=20, averaging_window=3, stop=True)
        # print("Curve detected")
        # time.sleep(1)
        # self.motors.set_base_speed(190)
        # self.motors.set_min_speed(175)
        # self.line_follow_time(0.75)
        # self.motors.set_motor_speeds_raw(180,180)
        # time.sleep(0.25)
        # self.motors.stop_motors()
        
        # STEP 2: Pick up the pet
        input("Enter to start step 2")
        self.arm.set_wrist_angle(0)

        arm_pos = [15,0,0]
        self.arm.set_arm_ik_position(15,5,wait_for_ack=True,timeout=1)
        # self.locate_pet(60,90,45,arm_pos,5, 0.2, 280)
        self.locate_pet_discrete([55,65,75],arm_pos)

        grab_pos = [15+11,-8,0]
        self.grab_pet_direct(grab_pos)
        time.sleep(1)

        self.arm.set_wrist_angle(180)
        self.arm.set_arm_angles(elbow=0,wait_for_ack=True,timeout=0.5)
        self.arm.set_arm_angles(shoulder=100, wait_for_ack=True,timeout=2)
        self.arm.set_turret_angle(90)
        self.arm.set_arm_angles(elbow=20, wait_for_ack=True,timeout=2)
        
        # self.arm.set_wrist_angle_unlock(180)
        # self.arm.set_arm_angles(elbow=0,wait_for_ack=True,timeout=0.5)
        # self.arm.set_turret_angle(90)
        # self.arm.set_arm_angles(shoulder=100, wait_for_ack=True,timeout=1.5)
        # self.arm.set_claw_angle(90)

        input("Enter to start step 3")

        # STEP 3: Move up the ramp until the third curve
        self.motors.set_base_speed(190)
        self.motors.set_min_speed(165)
        self.line_follow_time(1.5, stop=False)

        print("Step 2")      
        self.motors.set_base_speed(210)
        self.motors.set_min_speed(190)

        self.line_follow_time(2, stop=False)        
        print("Step 3")

        self.motors.set_base_speed(190)
        self.motors.set_min_speed(170)

        self.line_follow_until_curve(curve_threshold=7, max_threshold=20, averaging_window=3)
        self.motors.set_motor_speeds_raw(200,200)
        time.sleep(0.5)
        self.motors.stop_motors()

        # STEP 4: Drop first pet into chute

        input("Enter to start step 4")
        
        self.drop_into_chute()

        # STEP 5: Pick up second pet

        input("Enter to start step 5")

        self.arm.set_wrist_angle(0)

        arm_pos = [15,0,0]
        self.arm.set_arm_ik_position(15,5,wait_for_ack=True,timeout=1.5)
        # self.locate_pet(60,90,45,arm_pos,5, 0.2, 280)
        self.locate_pet_discrete([130,115,100],arm_pos)

        grab_pos = [15+11,-6,0]
        self.grab_pet_direct(grab_pos)
        time.sleep(1)

        # STEP 6: Drop second pet into chute (same as step 4)

        input("Enter to start step 6")
        self.drop_into_chute()

        # STEP 7: Line follow for around 1 sec, then pick up 3rd pet, then drop into basket

        input("Enter to start step 7")
        self.motors.set_base_speed(180)
        self.motors.set_min_speed(165)
        self.line_follow_time(1)

        arm_pos = [15,15,0]
        self.arm.set_arm_ik_position(15,20,wait_for_ack=True,timeout=1.5)
        # self.locate_pet(60,90,45,arm_pos,5, 0.2, 280)
        self.locate_pet_discrete([165,150,135,120,105,90],arm_pos)

        grab_pos = [15+11,9,0]
        self.grab_pet_direct(grab_pos)
        time.sleep(1)

        self.drop_into_basket()
        self.neutral_pos()

    def neutral_pos(self):
        self.arm.set_arm_angles(90, None, 120, wait_for_ack=True, timeout=1)
        self.arm.set_arm_angles(90, 150, 120, wait_for_ack=True, timeout=1)
        self.arm.set_arm_angles(90, 150, 165, wait_for_ack=True, timeout=1)

    def drop_into_basket(self):
        self.arm.set_wrist_angle_unlock(180)
        self.arm.set_arm_angles(elbow=0,wait_for_ack=True,timeout=0.5)
        self.arm.set_turret_angle(90)
        self.arm.set_arm_angles(shoulder=100, wait_for_ack=True,timeout=2)
        self.arm.set_claw_angle(90)

    def drop_into_chute(self):
        self.arm.set_arm_angles(90, 90, 0, wait_for_ack=True, timeout=1)
        self.arm.set_wrist_angle(90)
        self.arm.set_turret_angle(180, wait_for_ack=True, timeout=1)
        self.arm.set_wrist_angle(30)
        self.arm.set_arm_angles(elbow=50, wait_for_ack=True, timeout=1.5)
        self.arm.set_claw_angle(90)
        time.sleep(0.25)
        self.arm.set_turret_angle(90)
    
    def line_follow_until_curve(self, curve_threshold=5, max_threshold=40, 
                               averaging_window=10, debug=False, stop=True):
        """
        Follow line until a curve is detected using averaged curvature values.
        
        Args:
            curve_threshold: Average curvature threshold for curve detection (degrees).
                           Higher values = more pronounced curve needed to stop.
                           Typical values: 5-25 degrees
            max_threshold: Maximum curvature value to ignore outliers (degrees).
                          Values above this are considered noise/errors.
                          Typical value: 45-60 degrees
            averaging_window: Number of recent curvature values to average.
                            Default: 10 samples
            debug: Print debug information about curvature detection
        """
        # Start Line Following
        self.motors.start_line_following()
        
        # Initialize curvature history buffer
        curvature_history = []
        curve_detected = False
        
        if debug:
            print(f"🔄 Starting line follow until curve detection:")
            print(f"   Threshold: {curve_threshold}°")
            print(f"   Max threshold: {max_threshold}°")
            print(f"   Averaging window: {averaging_window} samples")
        
        while not curve_detected:
            # Get line points
            points = self.line_manager_1.get_line()
            
            # Update line following if line found
            line_status = self.line_manager_1.get_detection_status()
            if line_status.get('line_found', False) and points:
                self.motors.update_line_following(points)
                
                # Calculate current curvature
                current_curvature = self.motors.detect_curvature(points)
                
                
                # Filter out invalid readings
                if current_curvature is not None and abs(current_curvature) <= max_threshold:
                    print(current_curvature)
                    # Add to history (use absolute value for averaging)
                    curvature_history.append(abs(current_curvature))
                    
                    # Maintain window size
                    if len(curvature_history) > averaging_window:
                        curvature_history.pop(0)
                    
                    # Calculate average if we have enough samples
                    if len(curvature_history) >= min(5, averaging_window):  # Need at least 5 samples
                        avg_curvature = sum(curvature_history) / len(curvature_history)
                        
                        if debug and self.loop_count % 10 == 0:  # Print every 10 loops
                            print(f"   Current: {current_curvature:.1f}°, "
                                  f"Average ({len(curvature_history)} samples): {avg_curvature:.1f}°")
                        
                        # Check if average exceeds threshold
                        if avg_curvature >= curve_threshold:
                            curve_detected = True
                            print(f"🔄 Curve detected! Average curvature: {avg_curvature:.1f}° "
                                  f"(threshold: {curve_threshold}°)")
                            
                            # Show recent history
                            if debug:
                                print(f"   Recent values: {[f'{v:.1f}' for v in curvature_history[-5:]]}")
                    
                elif debug and current_curvature is not None:
                    print(f"   ⚠️ Ignoring outlier: {current_curvature:.1f}° (max: {max_threshold}°)")
            else:
                # No line found - could add line loss handling here
                if debug:
                    print("   ⚠️ No line detected")
            
            # Small delay to prevent excessive CPU usage
            time.sleep(0.025)
        
        # Stop line following
        if stop:
            self.motors.stop_line_following()
        
        if debug:
            print(f"✅ Stopped line following after curve detection")

    def line_follow_time(self, duration=1.0, stop=True):
        # Start Line Following

        self.motors.start_line_following()

        start_time = time.time()
        while (time.time()-start_time < duration):
            points = self.line_manager_1.get_line()
            line_status = self.line_manager_1.get_detection_status()
            if (line_status.get('line_found', False)):
                self.motors.update_line_following(points)

        if(stop):
            self.motors.stop_line_following()
    
    def line_follow_until_barrier(self, barrier_threshold=50, consecutive_detections=5, stop=True):
        """
        Follow line until a curve is detected using averaged curvature values.
        
        Args:
            curve_threshold: Average curvature threshold for curve detection (degrees).
                           Higher values = more pronounced curve needed to stop.
                           Typical values: 5-25 degrees
            max_threshold: Maximum curvature value to ignore outliers (degrees).
                          Values above this are considered noise/errors.
                          Typical value: 45-60 degrees
            averaging_window: Number of recent curvature values to average.
                            Default: 10 samples
            debug: Print debug information about curvature detection
        """
        # Start Line Following
        self.motors.start_line_following()
        
        # Initialize curvature history buffer
        barrier_count = 0
        barrier_detected = False
        
        while barrier_count < consecutive_detections:
            # Get line points
            barrier_percentage = self.get_barrier_data()
            if barrier_percentage > barrier_threshold:
                barrier_count += 1
            else: 
                barrier_count = 0
            
            # Small delay to prevent excessive CPU usage
            time.sleep(0.025)
        
        # Stop line following
        if stop:
            self.motors.stop_line_following()

    def turn_around(self, turn_right=True, starting_speed=50, min_speed=25, center_target=0.1, after_duration=0):
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

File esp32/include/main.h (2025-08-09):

#pragma once
#include <Arduino.h>

// arm pins
#define SERVO_BASE_PIN          14
#define SERVO_SHOULDER_L        13
#define SERVO_SHOULDER_R        12
#define SERVO_ELBOW_PIN         33
#define SERVO_WRIST_PIN         27
#define SERVO_CLAW_PIN          15

// motor pins
#define M1_PIN_FWD              20
#define M1_CHAN_FWD             0
#define M1_PIN_REV              21
#define M1_CHAN_REV             1

#define M2_PIN_FWD              19
#define M2_CHAN_FWD             2
#define M2_PIN_REV              22
#define M2_CHAN_REV             3

// reflectance sensor pins
#define ANALOG_PIN_R1           37  // GPIO37 = ADC1_CHANNEL_1
#define ANALOG_PIN_L1           38  // GPIO38 = ADC1_CHANNEL_2
#define ANALOG_PIN_R2           34  // GPIO34 = ADC1_CHANNEL_6
#define ANALOG_PIN_L2           35  // GPIO35 = ADC1_CHANNEL_7

// pwm settings
#define PWM_FREQ                500
#define PWM_RES_BITS            8

// line following params
#define K_P                     30.0
#define K_I                     0.0
#define K_D                     0.5
#define K_O                     2.0
#define TARGET_POSITION         150.0
#define CURRENT_POSITION        0.0
#define BASE_SPEED              150
#define SENSOR_THRESHOLD_R1     2.5
#define SENSOR_THRESHOLD_L1     2.5
#define SENSOR_THRESHOLD_R2     2.2
#define SENSOR_THRESHOLD_L2     2.3

// speed parameters
#define MOTOR_MIN_SPEED         0
#define MOTOR_MAX_SPEED         255
#define IDX_BASE_SPEED          45.0
#define IDX_SHOULDER_SPEED      30.0
#define IDX_ELBOW_SPEED         60.0
#define IDX_WRIST_SPEED         60.0

// servo pins
#define NUM_SERVOS              5
#define IDX_BASE                0
#define IDX_SHOULDER_L          1
#define IDX_SHOULDER_R          2
#define IDX_ELBOW               3
#define IDX_WRIST               4

// kinematics constants
#define ARM_L1                  14.5
#define ARM_L2                  12.547
#define ELBOW_OFFSET            40.0
#define DEG2RAD                 (3.14159265/180.0)
#define RAD2DEG                 (180.0/3.14159265)

// servo offset compensation
#define SHOULDER_R_OFFSET       174.0 
#define WRIST_LOWER_LIMIT       -75
#define WRIST_UPPER_LIMIT       105
#define WRIST_SERVO_ALIGNED     75 + 22      // servo angle when aligned with second arm
#define BASE_SERVO_OFFSET       10           // base servo offset from 0deg


// forward declarations
class MotorController;
class ServoController;
class PiComm;
struct PiCommand;

// function declarations
void handleLocalCommand(String cmd);
void printSystemStatus();
void emergencyStop();

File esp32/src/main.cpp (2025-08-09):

#include <Arduino.h>
#include "main.h"
#include "arm.h"
#include "motor.h"
#include "linefollower.h"
#include "pi.h"
#include "input_display.h"

// Create controller instances
ServoController arm;
MotorController motors;
LineFollower sensorLineFollower(&motors);
PiComm piComm(&motors, &arm, &sensorLineFollower);
InputDisplay inputDisplay;

// System state
bool systemInitialized = false;

void setup() {
  Serial.begin(921600);
  
  motors.init();
  arm.init();
  
  motors.setMinSpeed(MOTOR_MIN_SPEED);
  motors.setMaxSpeed(MOTOR_MAX_SPEED);  
  
  sensorLineFollower.setBaseSpeed(BASE_SPEED);
  sensorLineFollower.setTargetPosition(TARGET_POSITION);
  sensorLineFollower.setPID(K_P, K_I, K_D);
  sensorLineFollower.setKo(K_O);
  sensorLineFollower.setSensorThreshold(LineFollower::R1, SENSOR_THRESHOLD_R1);
  sensorLineFollower.setSensorThreshold(LineFollower::L1, SENSOR_THRESHOLD_L1);
  sensorLineFollower.setSensorThreshold(LineFollower::R2, SENSOR_THRESHOLD_R2);
  sensorLineFollower.setSensorThreshold(LineFollower::L2, SENSOR_THRESHOLD_L2);

  if (!inputDisplay.init()) {
    return;
  }
  
  delay(1000);
  arm.resetPosition();
  
  systemInitialized = true;
  // inputDisplay.setReady(true); 
}

void loop() {
  if (!systemInitialized) return;
  
  arm.update();
  inputDisplay.update();
  
  if (Serial.available()) {
    String command = Serial.readStringUntil('\n');
    command.trim();
    
    if (command.length() > 0) {
      if (command.equals("PI:READY")) {
        inputDisplay.setReady(true);
        inputDisplay.setSystemState(STATE_READY);
        inputDisplay.forceDisplayUpdate();
        Serial.println("OKAY");
      } 
      else if (command.startsWith("PI:")) {
        PiResponse response = piComm.processCommand(command);
        piComm.sendResponse(response);
      } 
      else {
        handleLocalCommand(command);
      }
    }
  }
  
  delay(10);
}

void handleLocalCommand(String cmd) {
  cmd.toLowerCase();
  
  if (cmd == "status") {
    printSystemStatus();
  }
  else if (cmd == "sensors") {
    sensorLineFollower.printSensorValues();
  }
  else if (cmd == "arm") {
    arm.printStatus();
  }
  else if (cmd == "lf") {
    sensorLineFollower.printStatus();
  }
  else if (cmd == "test") {
    Serial.println("Testing Pi command: PI:STATUS");
    PiResponse response = piComm.processCommand("PI:STATUS");
    piComm.sendResponse(response);
  }
  
  else if (cmd == "input" || cmd == "display") {
    inputDisplay.printStatus();
  }
  else if (cmd == "mode") {
    Serial.print("Current mode: "); Serial.print(inputDisplay.getPetCount());
    Serial.print(" pets"); Serial.println(inputDisplay.getSystemState());
  }
  else if (cmd == "teststart") {
    Serial.println("Simulating start button press...");
    // Test ESP command through Pi system
    PiResponse response = piComm.processCommand("ESP:START," + String(inputDisplay.getPetCount()));
    piComm.sendResponse(response);
  }
  else if (cmd == "testreset") {
    Serial.println("Simulating reset command...");
    // Test ESP command through Pi system
    PiResponse response = piComm.processCommand("ESP:RESET");
    piComm.sendResponse(response);
  }
  else if (cmd == "health") {
    Serial.print("InputDisplay healthy: "); 
    Serial.println(inputDisplay.isSystemHealthy() ? "YES" : "NO");
  }
  
  else {
    Serial.println("=== Available Commands ===");
    Serial.println("System: status, sensors, arm, lf, test");
    Serial.println("Display: input, mode, teststart, testreset");
    Serial.println("Pi commands start with 'PI:'");
  }
}

void printSystemStatus() {
  Serial.println("\n=== COMPLETE SYSTEM STATUS ===");
  Serial.print("System Initialized: "); Serial.println(systemInitialized ? "Yes" : "No");
  
  Serial.println("\n--- Motor Controller ---");
  motors.printStatus();
  
  Serial.println("\n--- Line Follower ---");
  sensorLineFollower.printStatus();
  
  Serial.println("\n--- Arm Controller ---");
  arm.printStatus();
  
  Serial.println("===============================\n");
}

void emergencyStop() {
  Serial.println("EMERGENCY STOP ACTIVATED!");

  motors.stop();
  sensorLineFollower.stop();
  arm.stopAll();
  
  inputDisplay.showError("EMERGENCY STOP");
  inputDisplay.setSystemState(STATE_ERROR);

  Serial.println("ESP:EMERGENCY_STOP");
}

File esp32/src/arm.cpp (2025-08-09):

#include "arm.h"
#include "main.h"

ServoController::ServoController() : last_millis(0), last_ik_millis(0),
    ik_vel_enabled(false), ik_target_x(0), ik_target_y(0), ik_vx(0), ik_vy(0),
    wrist_lock_enabled(true), wrist_lock_angle(0), initialized(false) {
  
  // set max speeds
  max_speed[IDX_BASE] = IDX_BASE_SPEED;
  max_speed[IDX_SHOULDER_L] = IDX_SHOULDER_SPEED;
  max_speed[IDX_SHOULDER_R] = IDX_SHOULDER_SPEED;
  max_speed[IDX_ELBOW] = IDX_ELBOW_SPEED;
  max_speed[IDX_WRIST] = IDX_WRIST_SPEED; 
  
  // set home positions - account for fixed shoulder offset and base offset
  for (int i = 0; i < NUM_SERVOS; i++) {
    if (i == IDX_BASE) {
      // Base home position: user angle 90° maps to servo angle 100°
      float home_user_angle = 90.0;
      float home_servo_angle = map(home_user_angle, 0, 180, BASE_SERVO_OFFSET, 180 - BASE_SERVO_OFFSET);
      home_pos[i] = home_servo_angle;
      current_pos[i] = home_servo_angle;
      target_pos[i] = home_servo_angle;
    }
    else if (i == IDX_SHOULDER_L) {
      float desired_home = 90.0;
      if (desired_home > SHOULDER_R_OFFSET) {
        desired_home = SHOULDER_R_OFFSET;
      }
      home_pos[i] = desired_home;
      current_pos[i] = desired_home;
      target_pos[i] = desired_home;
    }
    else if (i == IDX_SHOULDER_R) {
      float right_home = constrain(SHOULDER_R_OFFSET - home_pos[IDX_SHOULDER_L], 0, 180);
      home_pos[i] = right_home;
      current_pos[i] = right_home;
      target_pos[i] = right_home;
    }
    else {
      home_pos[i] = 90.0;
      current_pos[i] = 90.0;
      target_pos[i] = 90.0;
    }
    speed_cmd[i] = 0.0;
  }
}

void ServoController::init() {
  // initialize servo manager
  ServoManager::init();
  
  // servo pin assignments
  int servo_pins[NUM_SERVOS] = {
    SERVO_BASE_PIN, SERVO_SHOULDER_L, SERVO_SHOULDER_R, 
    SERVO_ELBOW_PIN, SERVO_WRIST_PIN
  };
  
  // attach servos
  for (int i = 0; i < NUM_SERVOS; i++) {
    if (!servos[i].attach(servo_pins[i], i + 4)) {  // pin and channel
      Serial.print("Failed to attach servo ");
      Serial.println(i);
      return;
    }
    // Write the correct position
    servos[i].write(current_pos[i]);
    delay(100);  // small delay between servo initializations
  }
  
  // attach claw
  if (!claw.attach(SERVO_CLAW_PIN, 9)) {  // pin and channel
    Serial.println("Failed to attach claw servo");
    return;
  }
  claw.write(90);
  
  last_millis = millis();
  last_ik_millis = millis();
  
  // seed IK target
  Point W = forwardKinematics(current_pos[IDX_SHOULDER_L], current_pos[IDX_ELBOW]);
  ik_target_x = W.x;
  ik_target_y = W.y;
  
  initialized = true;
  Serial.println("Servo controller initialized with EXACT working kinematics pattern");
  Serial.print("Arm geometry: L1="); Serial.print(ARM_L1); 
  Serial.print("cm L2="); Serial.print(ARM_L2); 
  Serial.print("cm ELBOW_OFFSET="); Serial.print(ELBOW_OFFSET); Serial.println("°");
  Serial.print("Max reach: "); Serial.print(ARM_L1 + ARM_L2);
  Serial.print("cm Min reach: "); Serial.println(fabs(ARM_L1 - ARM_L2));
}
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

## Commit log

2025-06-24 add: launch-platform-bottom
    [launch-platform-bottom.dxf]
2025-06-25 add: launch-platform-connector
    [launch-platform-connector.dxf]
2025-06-26 add: launch-platform-top
    [launch-platform-top.dxf]
2025-06-27 add: lids
    [lids.dxf]
2025-06-28 add: mid1
    [mid1.dxf]
2025-06-29 add: mid2
    [mid2.dxf]
2025-06-30 add: wall
    [wall.dxf]
2025-07-01 add: bottom-lid
    [bottom-lid.dxf]
2025-07-05 add: top-lid
    [top-lid.dxf]
2025-07-08 add: folder for arm cad
    [arm1-bottom.dxf]
2025-07-09 add: arm1-servo-side
    [arm1-servo-side.dxf]
2025-07-10 add: arm1-side
    [arm1-side.dxf]
2025-07-11 add: arm1-top
    [arm1-top.dxf]
2025-07-12 add: arm2-servo-side
    [arm2-servo-side.dxf]
2025-07-13 add: arm2-side
    [arm2-side.dxf]
2025-07-14 add: arm2-top-bottom
    [arm2-top-bottom.dxf]
2025-07-15 add: arm3-servo-side
    [arm3-servo-side.dxf]
2025-07-16 add: arm3-side
    [arm3-side.dxf]
2025-07-16 move cad to discrete folder
    [bracket-inside.dxf, bracket-outside.dxf, bracket-outside2.dxf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]
2025-07-16 launcher stuff
    [bracket-inside.dxf, bracket-outside.dxf, bracket-outside2.dxf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]
2025-07-16 add: arm.h
2025-07-16 add: motor.h
2025-07-16 add: arm.cpp
2025-07-16 add: motor.cpp
2025-07-17 add: arm3-top-bottom
    [arm3-top-bottom.dxf]
2025-07-18 add: base-plate
    [base-plate.dxf]
2025-07-19 add: base-servo-bracket
    [base-servo-bracket.dxf]
2025-07-21 add: arm header
2025-07-21 add: custom servo library header
2025-07-21 add: motor header
2025-07-21 add: arm methods
2025-07-21 add: custom servo library methods
2025-07-21 add: motor methods
2025-07-21 edit: motor header to solely include motor control
2025-07-21 edit: made motor controller discrete and separate
2025-07-21 edit: limit switch pin
2025-07-21 edit: rename length constants for motor conflict
2025-07-21 add library for motor
2025-07-22 ADD EVERYTHING BRO
    [bottom-lid.dxf, bracket-inside.dxf, bracket-outside.dxf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]
2025-07-22 edit: fix pwm channel allocation bug
    [arm.cpp]
2025-07-22 remove redundant pin declarations to avoid 'expected unqualified-id before numeric constant' error
2025-07-22 add: function prototypes to avoid error
    [main.cpp]
2025-07-23 separate motor from line follower more clearly
2025-07-24 replace with constants from header file
    [linefollower.cpp]
2025-07-24 add: servo speed params to main
2025-07-24 add: use speed constants for servo speed
2025-07-24 pi stuff + arm lock angle changes + claw reset pos change
    [arm.cpp, arm_controller.py, camera_manager.py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]
2025-07-24 git weirdness
    [CamMount_v1.stl, CamMount_v2.stl, CamMount_v2_camholder.stl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]
2025-07-24 add: function header for pid setting command
2025-07-24 add: function for pid setting command
2025-07-24 edit: rename target position folder to prevent naming conflict with arm
2025-07-24 edit: documentation for sensor threshold command
2025-07-24 add: function for setting sensor thresholds
2025-07-24 add: sensor threshold handler to command handler
2025-07-24 add: dash skip functionality for ss now
    [pi.cpp]
2025-07-30 add: shoulder calibration method declarations
2025-07-30 motor backward speed fix + reflectnace sensor commands
    [motor.cpp, pi.cpp, robot_controller.py]
2025-07-30 edit: move servo pin defines to main
2025-07-30 edit: fix shoulder speed bug
    [pi.cpp]
2025-07-30 edit: formatting, corrected function signature
    [main.h]
2025-07-30 edit: slaying the arm
2025-07-31 edit: fix code for changed shoulder, IK, IV
    [arm.cpp]
2025-07-31 edit: servo shoulder pins, arm lengths, offset definitions
2025-07-31 edit: use correct arm code
    [arm.cpp]
2025-07-31 edit: motor code formatting
2025-07-31 edit: motor header formatting
2025-07-31 remove: limit switch code
2025-07-31 fix: wrist lock resting angle
    [arm.cpp]
2025-07-31 fix: wrist servo lock angle
    [main.h]
2025-08-01 edit: add ko to set pid
2025-08-01 add: motor polling command
2025-08-01 fix: reflectance sensor polling command bug
    [pi.cpp]
2025-08-01 fix: motor speed polling command bug with piresponse
    [pi.cpp]
2025-08-01 edit: string char concatenation fix
    [pi.cpp]
2025-08-01 Update linefollower.cpp
    edit: use 4 sensors for line following
2025-08-02 add: clear speed command prototype
2025-08-02 add: fix for servo speeds and inverse vel
    [arm.cpp]
2025-08-03 remove: wrist manual override timer
2025-08-05 edit: remap pin assignments
2025-08-07 edit: fix ready waiting
    [input_display.cpp]
2025-08-26 add: wheel cover cad
    [barrier.gcode.3mf, barrier.step, dawheel.step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]
2025-08-26 add: rev2 arm cad
    [KJY SFHKJSDF.gcode.3mf, arm1-hole.3mf, arm1-hole.stl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]
2025-08-26 add: rev3 arm cad
    [arm1-1.3mf, arm1-1.step, arm1-2.step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]
2025-09-04 revise markdown
    Updated README to include detailed project description, demonstration videos, quick start guide, system architecture, firmware and software installation instructions, command protocol, core algorithm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
2025-09-04 edit: cad
